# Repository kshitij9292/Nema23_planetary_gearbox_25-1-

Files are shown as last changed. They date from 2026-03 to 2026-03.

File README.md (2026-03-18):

High-Torque NEMA 23 Planetary Gearbox (25:1)




A high-precision, 3D-printable 25:1 planetary gearbox designed for NEMA 23 stepper motors. This project features a dual-stage reduction and an integrated custom ball-race bearing system to handle high axial loads—ideal for high-resolution tracking applications like the Printonian Telescope or robotic actuators.
🛠 Project Overview

Standard 3D-printed gearboxes often struggle with axial load and backlash. This design addresses those issues by:

    Dual-Stage 5:1 Reduction: Achieving a total 25:1 ratio for massive torque and sub-degree resolution.

    Integrated 8mm Ball Race: A custom-designed thrust bearing using 25x 8mm steel balls to ensure smooth rotation under heavy weight.

    Hybrid Construction: Optimized for a mix of 3D-printed gears and standardized steel hardware (SKF bearings and M4/M5 fasteners).

📦 Bill of Materials (BOM)
⚙️ Mechanical Components
Item	Part Number/Spec	Quantity	Purpose
Primary Bearing	SKF 608-2ZZ	2	Main axis support
Planet Bearings	SKF 625-2Z	2	Internal gear stability
Thrust Bearings	8mm Steel Balls	25	Custom ball-race assembly
Main Axis	Nema2356_axis	1	Power transfer
🔩 Fasteners

    M5x25mm SHCS: 10x (Main housing assembly)

    M4x16mm BHSF: 4x (Component mounting)

    M5x25mm BHSF: 3x (Secondary plate attachment)

    M4 Hex Nuts: 4x (Retention)

🖨 Recommended Print Settings

To ensure gear longevity and heat resistance (especially near the NEMA 23 motor):

    Material: ASA or PETG (Highly recommended for the Sun gear and Motor Plate).

    Walls: 6 perimeters (for tooth strength).

    Infill: 40% Gyroid.

    Layer Height: 0.15mm (for smooth gear mesh).

    Horizontal Expansion: Calibrate your printer to ±0.02mm to minimize backlash.

🔧 Assembly Sequence

    Motor Prep: Press-fit the Sun gear onto the NEMA 23 shaft. Secure with a set screw if applicable.

    First Stage: Assemble the first three planets onto the carrier using the SKF 625-2Z bearings.

    The Race: Clean the 8mm steel balls and apply a thin layer of lithium grease to the printed race. Carefully place all 25 balls into the channel.

    Final Stack: Layer the second stage carrier and the top housing.

    Closure: Use the M5x25mm bolts in a star pattern to ensure even pressure across the planetary gears.

📐 Calculated Performance

With a standard 1.8° NEMA 23 motor:

    Steps per Revolution: 40,000 (at 1/16 microstepping).

    Resolution: 0.009° per step.

    Mechanical Advantage: 25x Input Torque (minus efficiency losses).

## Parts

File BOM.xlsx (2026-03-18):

Part Number | Part Name | Description | Quantity
NEMA_23 | NEMA_23 | Main Assembly | 1
BSHCS M5x25 | Hex Socket Head Screw | M5x0.8 x 25mm | 10
BHSFCHCS M4x16 | Flat Countersunk Screw | M4x16mm | 4
HNS1 M4 | Hex Nut Style 1 | M4 Nut | 4
BHSFCHCS M5x25 | Flat Countersunk Screw | M5x25mm | 3
NEMA_23... | Nema23_planetary_gearbox | Main Gearbox Assembly | 1
Nema2356_contact | Nema2356_contact | Interface Plate | 1
Nema2356_screv | Nema2356_screv | Gearbox Screws | 4
Nema2356_gultnis | Nema2356_gultnis | Support/Housing | 2
Nema2356_axis | Nema2356_axis | Main Drive Axis | 1
planet | planet | Planetary Gears | 6
SKF_608-2ZZ | SKF_608-2ZZ | 8x22x7mm Bearing | 2
BSHCS M4x25 | Hex Socket Head Screw | M4x0.7 x 25mm | 1
SB-8-STL | 8mm Steel Ball | Precision Bearing Balls | 25

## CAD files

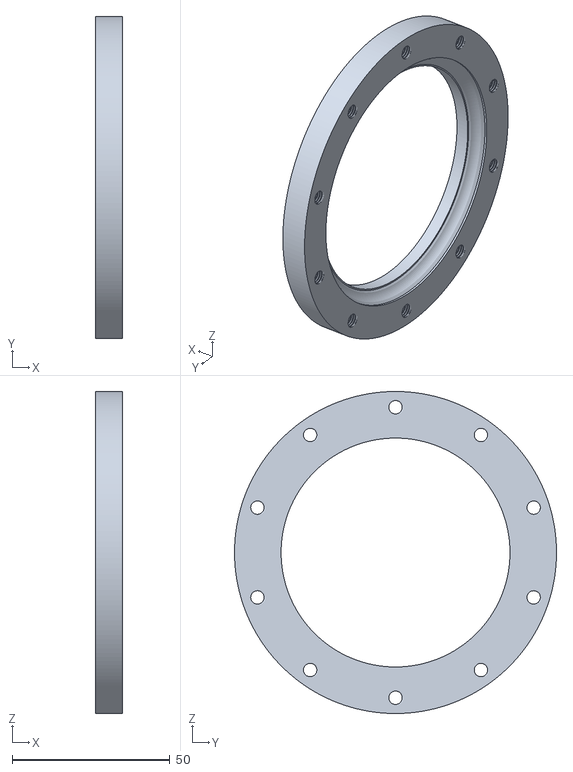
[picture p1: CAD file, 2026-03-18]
CAp.stl
8.50 x 102.0 x 102.0

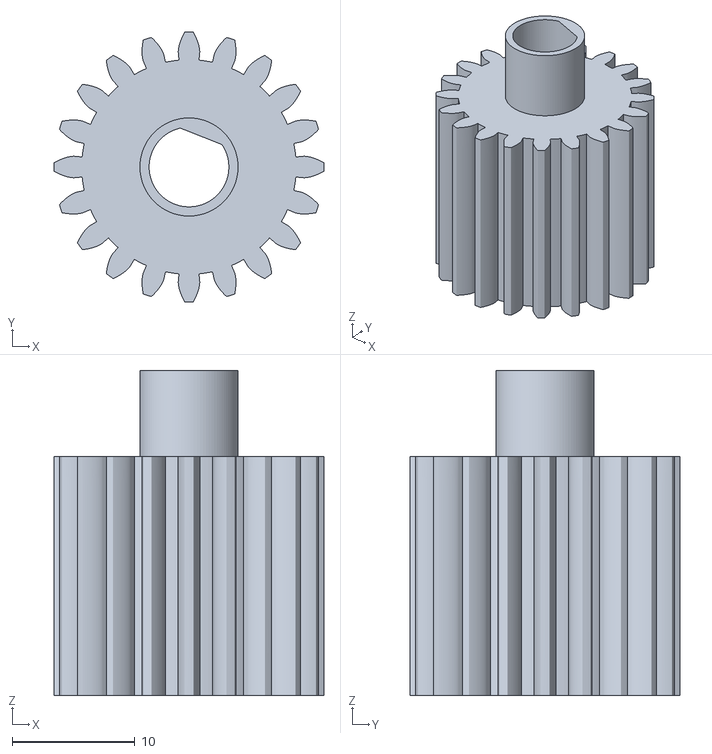
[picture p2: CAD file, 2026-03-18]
sun.stl
22.0 x 22.0 x 26.5

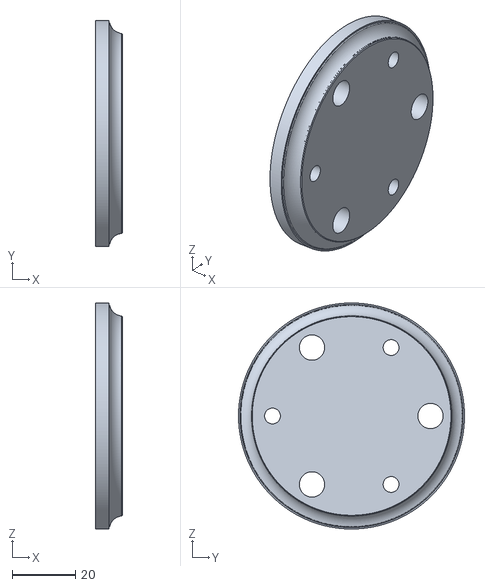
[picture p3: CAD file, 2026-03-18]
Outmount1.stl
8.50 x 71.5 x 71.5

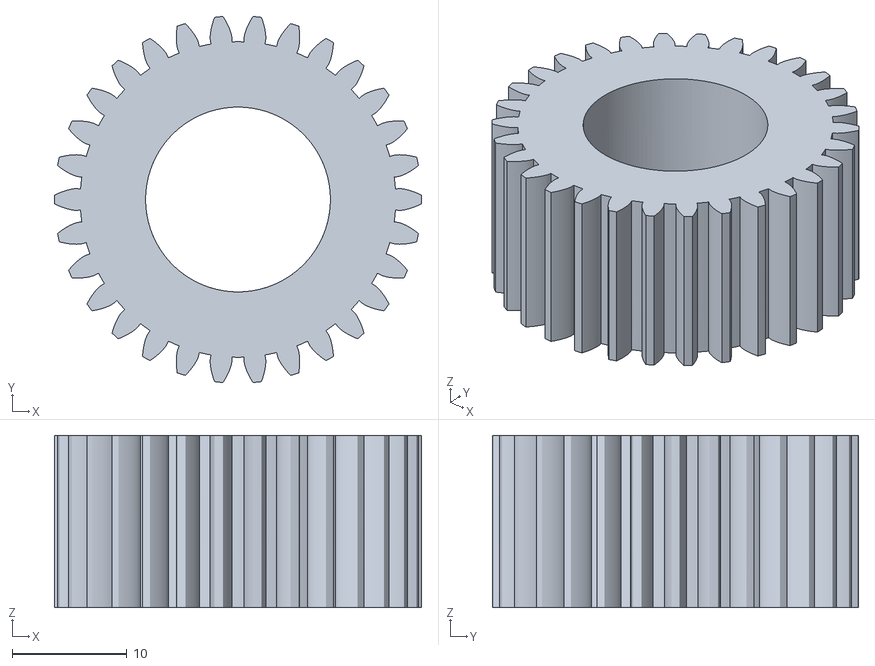
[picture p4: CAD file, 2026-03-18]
planet.stl
32.0 x 31.9 x 15.0

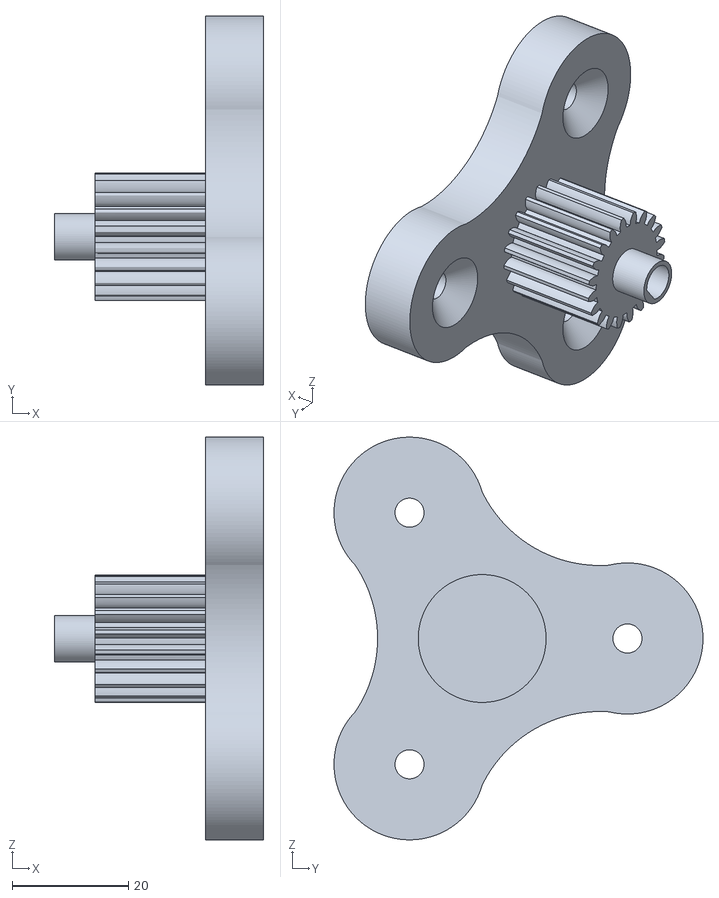
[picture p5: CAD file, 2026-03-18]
spider1.stl
36.0 x 63.5 x 69.3

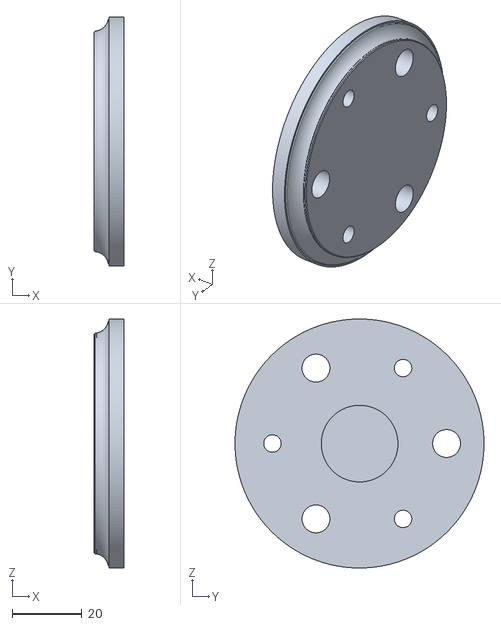
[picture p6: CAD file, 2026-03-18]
Outmount2.stl
8.50 x 71.5 x 71.5

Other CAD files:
CAp (2) (1).stl
